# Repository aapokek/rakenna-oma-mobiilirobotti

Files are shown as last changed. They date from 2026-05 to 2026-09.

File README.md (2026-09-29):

<div align="center">

# 🤖 Rakenna oma mobiilirobotti 🤖

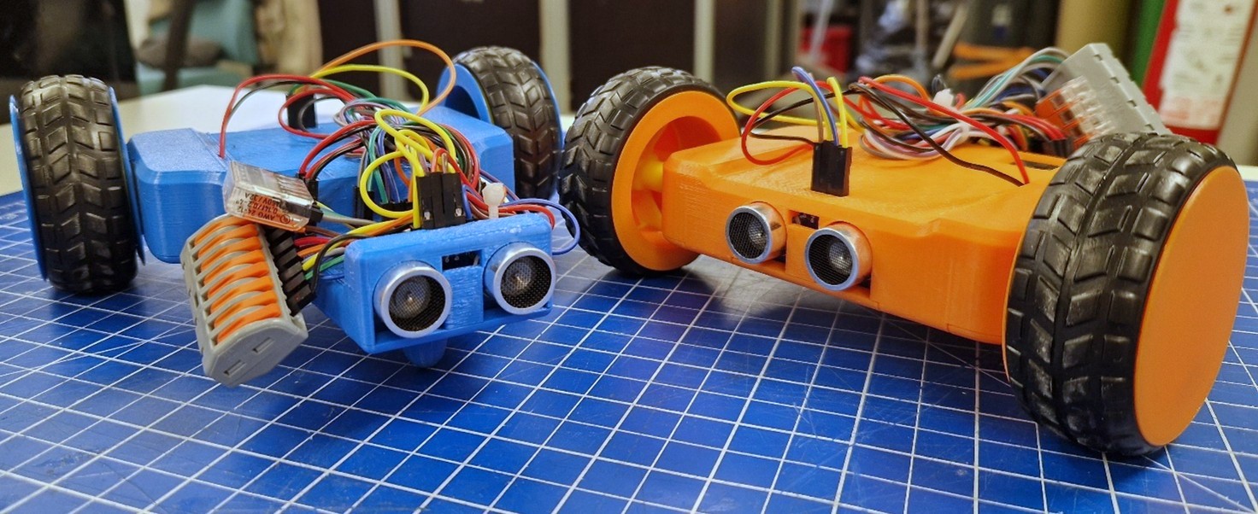
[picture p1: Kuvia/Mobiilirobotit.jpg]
Mobiilirobotit


**Rakenna oma WiFi-ohjattava mobiilirobotti törmäyksenestolla alusta loppuun!**



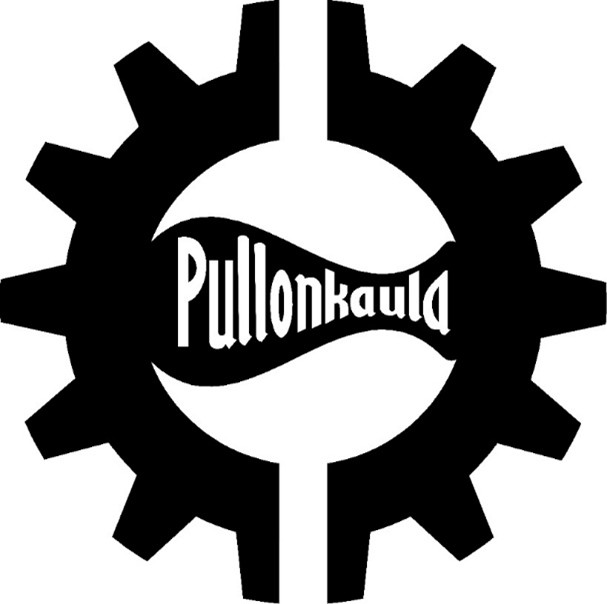
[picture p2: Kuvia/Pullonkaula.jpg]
Pullonkaula-kerho logo


*Pullonkaula ry*

</div>

---

## 📖 Tietoa projektista

Rakenna oma mobiilirobotti! Tämä projekti on alun pitäen saanut alkunsa Tampereen kaupungin Masseista mahiksia -tapahtumana syksyllä 2026. Tapahtumassa yläkoululaiset pääsivät rakentamaan oman mobiilirobotin, jota ohjataan älypuhelimella WiFin välityksellä. Robotti sisältää myös yksinkertaisen törmäyksenestojärjestelmän ultraääniantureiden avulla. Robotin kasausprosessi opettaa käytännön läheisesti sulautettujen järjestelmien toiminnan eli sen miten anturit ja toimilaitteet toimivat yhdessä!

Robotin kasaaminen ohjatusti sopii erinomaisesti kaikille – aiempaa kokemusta ei vaadita! Kokoneemmat rakentelijat voivat rakentaa robotin helposti itsenäisesti yksityiskohtaisen dokumentaation avulla!

---

## ✨ Ominaisuudet

- 📱 **WiFi-ohjaus** älypuhelimella selaimen kautta
- 🚧 **Törmäyksenesto** edessä ja takana
- 🖨️ **3D-tulostettu runko**
- ⚡ **AA-paristoilla** toimiva
- 🔧 **Helppo koota**
- 💰 **Kustannustehokas** – noin 20 € / kpl

---

## 🧰 Komponentit

| Komponentti | Määrä | Tehtävä |
|---|---|---|
| ESP8266 D1 mini | 1 | Mikrokontrolleri – robotin "aivot" |
| MP1584EN | 1 | Jännitteenmuuntaja (6V → 3.3V) |
| L298N mini + 470 µF | 1 | Moottorinohjain |
| HC-SR04 | 2 | Ultraäänianturit törmäyksenestoon |
| TT-moottori (1:48) | 2 | Liike |
| Rengas | 2 | Liike |
| 4×AA paristokotelo | 1 | Virtalähde |
| AA paristo (1.5 V) | 4 | Virtalähde |
| Vipuliittimet (3-, 5-, 8-napainen) | 1 kpl/tyyppi | Johdotus ilman juottamista |
| 0-0 hyppykaapelit | 8 | Kommunikaatiojohdot |
| 0-1 hyppykaapelit | 12 | Virtajohdot |
| M2×6 mm ruuvi | 3 | Rungon kiinnitys |
| Nippuside | 2 | Johtojen siistiminen |

> **Työkalut:** Tietokone, USB-C-kaapeli, ristipääruuvimeisseli, sivuleikkurit tai sakset

---

## 📁 Projektin rakenne

```
📦 Rakenna oma mobiilirobotti
├── 📂 3D-mallit
│   ├── 📂 Solidworks          ← Alkuperäiset SolidWorks-tiedostot
│   │   ├── Komponentit
│   │   └── Tulostettavat osat
│   ├── 📂 STEP                ← Universaali 3D-formaatti
│   └── 📂 STL                 ← Suoraan 3D-tulostimeen/Sliceriin!
├── 📂 Dokumentaatio
│   ├── Kasausohje (.pdf & .docx)
│   └── Build instructions (.pdf & .docx)
├── 📂 Koodit
│   └── Mobiilirobotin_koodi
│       └── Mobiilirobotin_koodi.ino   ← Arduino-koodi ESP8266:lle
└── 📂 Kuvia
    ├── Mobiilirobotin kytkentäkaavio.png
    ├── Mobiilirobotit.jpg
    ├── Kayttoliittyma.jpg
    └── Pullonkaula.jpg
```

---

## 🚀 Pikaopas kasaukseen

> 📄 Löydät täyden, yksityiskohtaisen ohjeen hakemistosta [`Dokumentaatio/`](Dokumentaatio/)  
> - Suomeksi: *Rakenna oma mobiilirobotti – Kasausohje* (.pdf / .docx)  
> - In English: *Build your own mobile robot – Build instructions* (.pdf / .docx)  
> 🎬 Tai katso kasausvideo: [youtu.be/AeR3-ane96E](https://youtu.be/AeR3-ane96E)

### 1️⃣ Koodin asennus

<details>
<summary><b>Asenna Arduino IDE</b></summary>

1. Mene osoitteeseen [arduino.cc/en/software](https://www.arduino.cc/en/software)
2. Lataa **Arduino IDE** omalle käyttöjärjestelmällesi (Windows / macOS / Linux)
3. Asenna ohjelma normaalisti asennusvelhon ohjeiden mukaan
4. Käynnistä Arduino IDE

</details>

<details>
<summary><b>Asenna ESP8266-tuki Arduino IDE:hen</b></summary>

1. Avaa Arduino IDE ja mene **File → Preferences**
2. Lisää **Additional boards manager URLs** -kenttään:
   ```
   https://arduino.esp8266.com/stable/package_esp8266com_index.json
   ```
3. Mene **Tools → Board → Boards Manager**, hae `esp8266` ja asenna **ESP8266 by ESP8266 Community**
4. Valitse piiriksi **Tools → Board → ESP8266 Boards → LOLIN(WEMOS) D1 mini (clone)**

</details>

<details>
<summary><b>Asenna tarvittavat kirjastot</b></summary>

Seuraavat kirjastot täytyy asentaa ennen koodin lataamista. Kirjastot löytyvät Arduino IDE:n kirjastonhallinnasta (**Tools → Manage Libraries…**) tai GitHub-linkeistä.

| Kirjasto | Asennus |
|---|---|
| `ESP8266WiFi` | Tulee automaattisesti ESP8266-tuen mukana |
| `DNSServer` | Tulee automaattisesti ESP8266-tuen mukana |
| `LittleFS` | Tulee automaattisesti ESP8266-tuen mukana |
| `ESPAsyncTCP` | Hae nimellä **ESPAsyncTCP** kirjastonhallinnasta |
| `ESPAsyncWebServer` | Hae nimellä **ESPAsyncWebServer** kirjastonhallinnasta |

> ⚠️ Jos `ESPAsyncTCP` tai `ESPAsyncWebServer` eivät löydy kirjastonhallinnasta, asenna ne manuaalisesti GitHubista:
> - [ESPAsyncTCP](https://github.com/me-no-dev/ESPAsyncTCP) → Code → Download ZIP → **Sketch → Include Library → Add .ZIP Library**
> - [ESPAsyncWebServer](https://github.com/me-no-dev/ESPAsyncWebServer) → sama menettely

</details>

Avaa `Koodit/Mobiilirobotin_koodi/Mobiilirobotin_koodi.ino` Arduino IDE:ssä. Muokkaa **riveille 2 ja 3** robotille haluamasi WiFi-verkon nimi ja salasana:

```cpp
String robotName = "MunRobotti";
static const char* AP_PASSWORD = "OmaSalasana"; // 8–63 merkkiä
```

Yhdistä ESP8266 D1 mini USB-C-kaapelilla tietokoneeseen ja paina Arduino IDE:ssä vasemman yläkulman **→ (Upload)**. Koodi on latautunut onnistuneesti, kun näet ilmoituksen `Done uploading`.

### 2️⃣ Komponenttien asennus runkoon

Tulosta ensin 3D-tulostettavat osat `3D-mallit/STL/`-kansiosta: ylärunko, alarunko, paristopidike sekä renkaiden pöly- ja sisäkapselit (2 kpl kumpaakin).

Työnnä moottoreiden johdot ylärungon sivureikien läpi ja paina moottorit paikoilleen. Paina sitten ESP8266 D1 mini, MP1584EN, L298N mini sekä molemmat HC-SR04-anturit niille tulostettuihin loviin. Asenna lopuksi AA-paristot paristokoteloon (kytkin OFF-asennossa!) ja kiinnitä paristopidike paikoilleen. Asenna alarunko pohjaksi, mutta jätä ruuvit vielä kiinnittämättä.

### 3️⃣ Virtajohtojen kytkeminen

Kytke robotin 18 virtajohtoa (12 toteutetaan 0-1 hyppykaapeleilla) kytkentäkaavion mukaisesti: kaikki maajohdot (GND) suurimpaan 8-napaiseen vipuliittimeen, paristoilta tuleva 6 V 3-napaiseen liittimeen ja MP1584EN:n antama 3.3 V 5-napaiseen liittimeen. Kytke myös moottorien johdot L298N minin MOTOR-A ja MOTOR-B -pinneihin.

### 4️⃣ Kommunikaatiojohtojen kytkeminen

Kytke 8 kommunikaatiojohtoa 0-0 hyppykaapeleilla ESP8266 D1 miniin kytkentäkaavion mukaisesti. Katso kytkentäkaavio alta! ⬇️

### 5️⃣ Testaus

> ⚠️ **Tarkastuta kytkennät huolella ennen testauksen aloittamista!**

Kiinnitä renkaat paikoilleen ja käynnistä robotti paristokotelon kytkimestä. Yhdistä puhelimella robotin WiFi-verkkoon ja avaa selaimessa `192.168.4.1` (jos ohjausnäkymä ei avaudu automaattisesti). Näytöllesi pitäisi ilmestyä alla näkyvä ohjausnäkymä.

<div align="center">
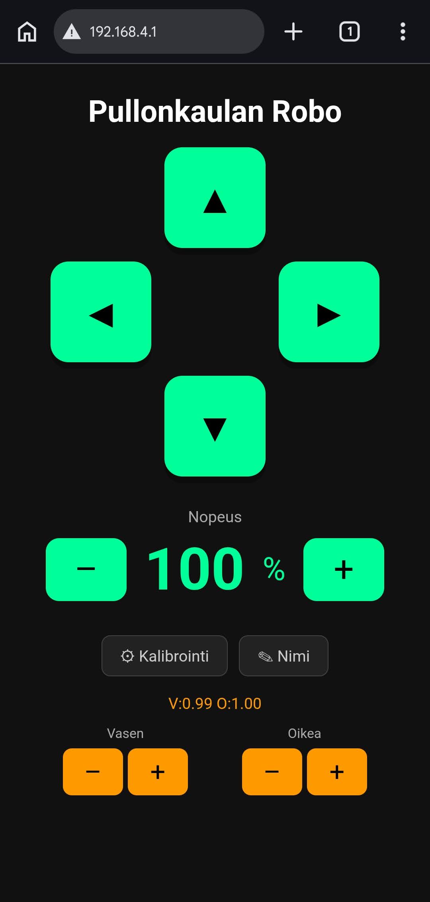
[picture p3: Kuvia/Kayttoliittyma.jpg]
Robotin ohjaukseen käytettävä käyttöliittymä puhelimen selaimessa

</div>

Ohjaa robottia napeista – jos jompikumpi moottori pyörii väärään suuntaan, vaihda sen virtajohdot päikseen.

### 6️⃣ Viimeistely

Ruuvaa pohja kiinni kolmella M2-ruuvilla ja siisti johdot kahdella nippusiteellä. Voit halutessasi kalibroida robotin kulkemaan suoraan sekä nimetä sen uudelleen käyttöliittymän valikoista.

---

## 🔌 Kytkentäkaavio

<details>
<summary><b>Näytä kytkentäkaavio</b></summary>

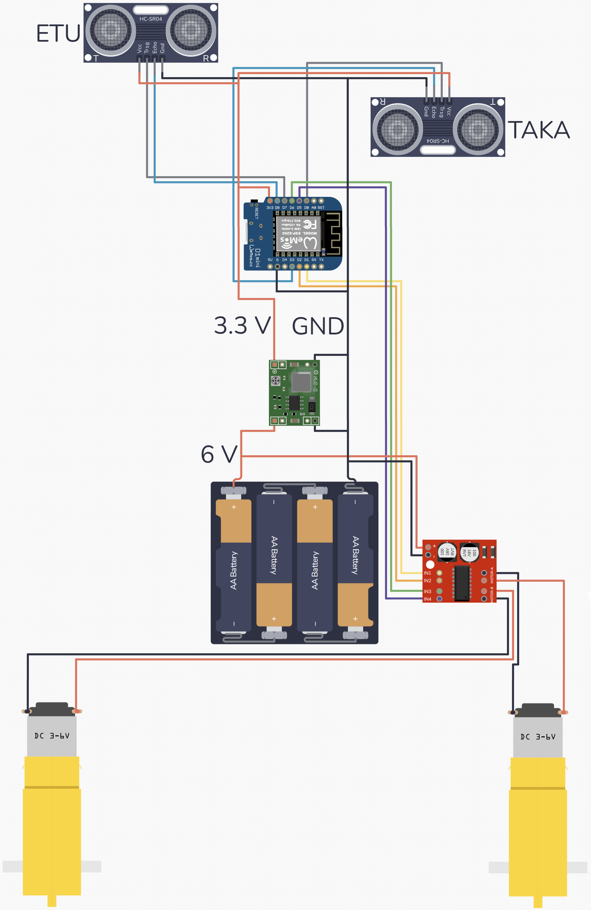
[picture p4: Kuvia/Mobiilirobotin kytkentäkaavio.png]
Kytkentäkaavio


**Pääperiaate:**
- 🔴 **6 V** (paristot) → L298N mini ja MP1584EN sisääntulo
- 🟠 **3.3 V** (MP1584EN ulostulo) → ESP8266 D1 mini ja HC-SR04-anturit
- ⚫ **GND** → kaikki komponentit yhteiseen 8-napaiseen vipuliittimeen

**Kommunikaatiojohdot (ESP8266):**

| L298N / HC-SR04 | ESP8266-pinni |
|---|---|
| IN1 | D1 |
| IN2 | D2 |
| IN3 | D6 |
| IN4 | D5 |
| Etuanturi Trig | D7 |
| Etuanturi Echo | D8 |
| Takaanturi Trig | D0 |
| Takaanturi Echo | D3 |

</details>

---

## 🎬 Kasausvideo

Kasausvideo (https://youtu.be/AeR3-ane96E)

---

## 📜 Lisenssi

Tämä projekti on kehitetty opetuksellisiin tarkoituksiin ja sen kaupallinen käyttö on kielletty.
Kehittäjä: **Aapo Kekkonen**

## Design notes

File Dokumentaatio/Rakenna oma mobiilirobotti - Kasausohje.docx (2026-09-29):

# Rakenna oma mobiilirobotti

# Kasausohje

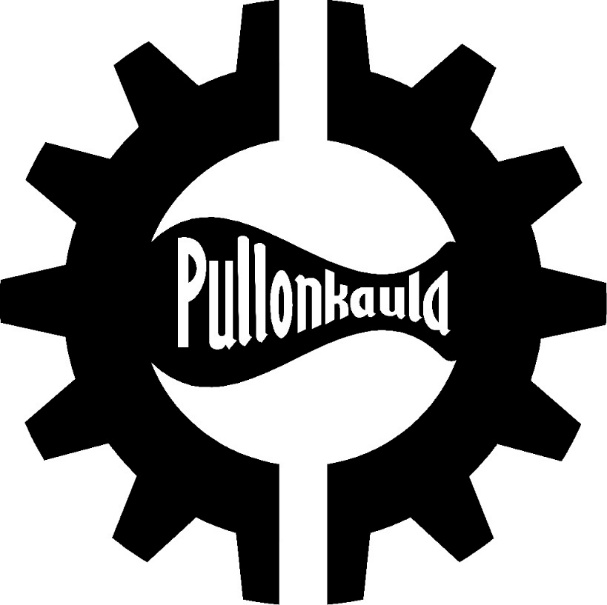
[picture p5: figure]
Blogi | Pullonkaula ry
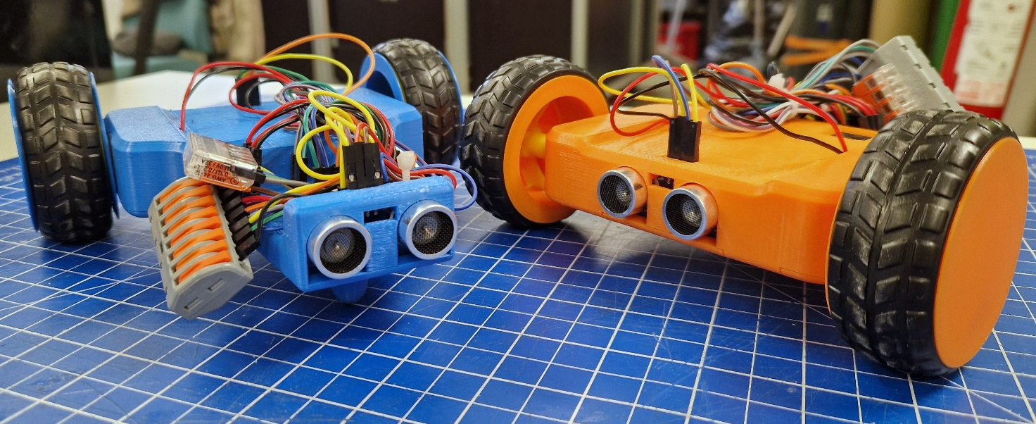
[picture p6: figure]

# Johdanto

Tervetuloa kasaamaan omaa mobiilirobottia!

Rakennettava mobiilirobotti ei jätä sinua kylmäksi, sillä sen ohjaus onnistuu omalla mobiililaitteellasi. Tämän lisäksi robotti sisältää yksinkertaisen törmäyksenestojärjestelmän.

Rakennettuasi robotin ymmärrät perusteet toimilaitteiden ja antureiden muodostamasta sulautetusta järjestelmästä! Samaa toimilaitteiden ja antureiden yhteyspeliä hyödyntävät myös muut robotit.

Tämä ohje aloittaa opastuksen luettelemalla tarvittavat komponentit ja antamalla lisätietoa komponenteista. Tämän jälkeen kasausprosessi käydään läpi yksityiskohtaisesti. Lopusta löydät vielä yksinkertaistetun kytkentäkaavion.

Oheisesta QR-koodista tai linkistä löydät videon kasausprosessista.

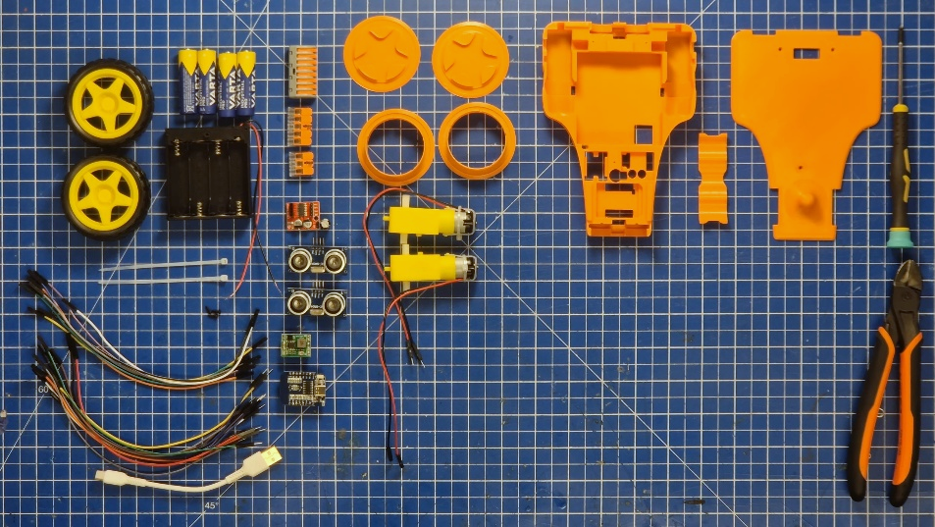
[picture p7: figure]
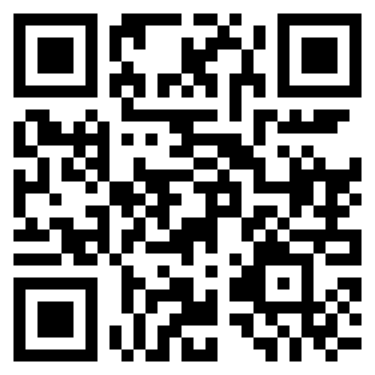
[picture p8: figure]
QR Code Image

https://youtu.be/AeR3-ane96E

Lisäksi oheisesta QR-koodista tai linkistä pääset robotin projektisivuille, josta löydät kaikki projektiin liittyvät tiedostot mukaan lukien myös tämän ohjeen!

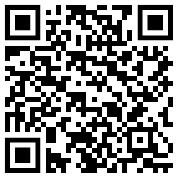
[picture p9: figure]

https://github.com/aapokek/Rakenna-oma-mobiilirobotti

# Tarvikkeet

Oheisesta taulukosta näet robotin rakentamiseen tarvittavat komponentit ja työkalut. Taulukko on jaoteltu 3D-tulostettaviin osiin, komponentteihin ja työkaluihin. 3D-tulostettavien osien tiedostot löydät projektikansiosta (Rakenna-oma-mobiilirobotti/3D-mallit/). Jos haluat tulostaa osia itse, hyödynnä siihen STL tai STEP tiedostoja. Lue halutessasi lisää komponenteista ja niiden käyttötarkoituksista seuraavasta kappaleesta!

# Tietoa komponenteista

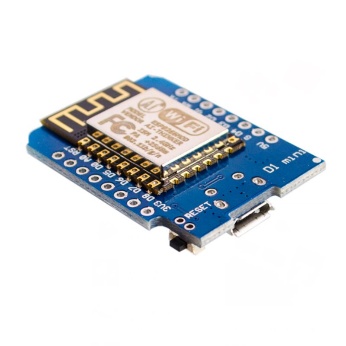
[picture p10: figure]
WeMos D1 Mini v2 NodeMCU ESP8266 IoT-kehitysalusta | ihmevekotin.fi

## ESP8266 D1 mini

ESP8266 D1 mini toimii robotin aivoina. Siihen ladataan ohjelmisto, jolla älypuhelimen ohjaussignaali muutetaan moottoreiden liikkeeksi. Lisäksi se lukee etäisyystietoja HC-SR04 etäisyysantureilta ja pysäyttää liikkeen havaitessa esteen riittävän lähellä. L298N mini moottorinohjain ja HC-SR04-anturit liitetään ESP8266 D1 minin sivussa oleviin nimettyihin liitinpinneihin.

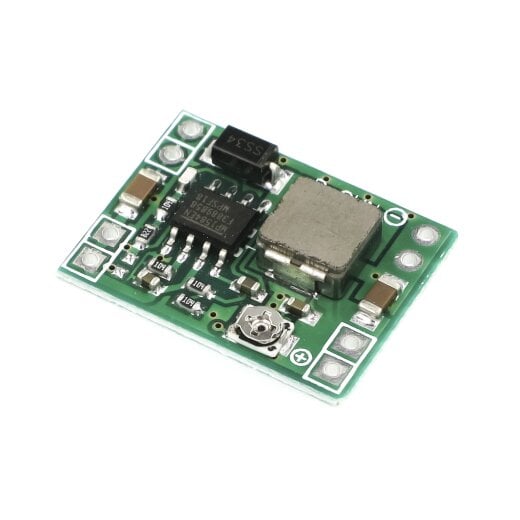
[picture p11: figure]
Mini DC-DC Step-down Spannungsregler MP1584EN Buck-virtamoduulin lähtö 0,8--20V 3A
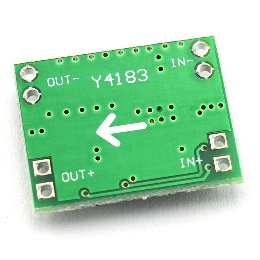
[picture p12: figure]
Opencircuit MP1584EN Mini Buck -muunnin 4,5 V - 28 V moduuli

## MP1584EN

MP1584EN on jännitteen muuntaja, joka muuntaa ja tasaa AA paristoilta tulevan 6 V jännitteen 3.3 volttiin. Tämä 3.3 V jännite syötetään ESP8266 D1 minille ja HC-SR04-antureille. Huomioithan komponentin takana olevan muunnoksen suuntanuolen. Voit liittää virtajohdon kumpaan tahansa vierekkäin olevaan pinniin.

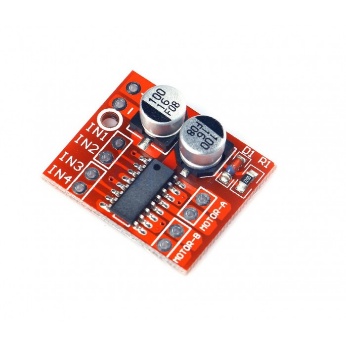
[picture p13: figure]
Mini L298N Motor Driver

## L298N mini + 470 µF

L298N mini ohjaa robotin moottoreita ESP8266 D1 minin
lähettämien signaalien mukaisesti. L298N minissä on 10
liitäntäpinniä. Komponentti saa virran suoraan paristolta +/-
pinneihin. Itse moottorit kiinnittyvät MOTOR-A ja MOTOR-B pinneihin. Vaihtamalla moottoripinnien kytkentä päikseen, moottorien pyörintäsuunta vaihtuu. Moottoreiden ohjaus
tapahtuu IN1, IN2, IN3 ja IN4 pinneillä, jotka kytketään
ESP8266 D1 miniin. Pinnit IN1 ja IN2 ohjaavat moottoria A ja IN3 ja IN4 moottoria B seuraavan taulukon mukaisesti:

Moottorin tila | IN1/IN3 | IN2/IN4
Eteenpäin | PWM | 0 V
Taaksepäin | 0 V | PWM
Valmiustila | 0 V | 0 V
Jarrutus | 3.3 V | 3.3 V

Taulukossa esiintyvän PWM:n (Pulse Width Modulation) avulla säädellään moottoreiden pyörimisnopeuksia. L298N minin virtapinneihin on juotettu 470 µF kondensaattori tasaamaan moottoreiden mahdollisia virtapiikkejä ja parantamaan moottoreiden suorituskykyä.

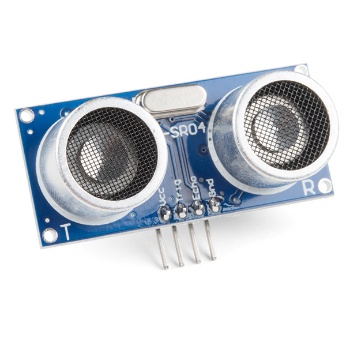
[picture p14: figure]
Ultrasonic Sensor - HC-SR04

## HC-SR04

HC-SR04 on ihmisen kuuloalueen ulkopuolisilla ultraäänipulssein toimiva etäisyysanturi. Sen toiminta perustuu esteen aiheuttamaan kaikuun. Anturi lähettää lyhyitä ultraäänipulsseja ja kuuntelee samaisten pulssien kaikuja. Anturi pystyy havaitsemaan esteen jopa 4 metrin päästä. HC-SR04:n 4 pinniä ovat VCC, GND, Trig ja Echo. Virta syötetään pinneihin VCC ja GND. Trig-pinniä hyödynnetään pulssin lähetykseen. Kaiun kuullessa anturi lähettää signaalin Echo-pinniin, joka rekisteröidään ESP8266:lla. Robotissa kyseisiä antureita käytetään törmäysten estoon eteenpäin tai taaksepäin liikkuessa. ESP8266 D1 mini laskee etäisyyden esteestä pulssin lähetyksen ja vastaanoton aikaerosta. Valmiissa koodissa robotti on asetettu pysähtymään asetetun nopeuden mukaan 20–50 cm etäisyydellä esteestä.

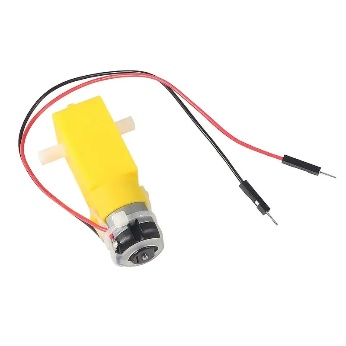
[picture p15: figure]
TT DC Motor with Plastic Gearbox – 1:48 Dual Shaft with Wires – Voltaat

## Moottorit

Robottia liikuttaa pienet 1:48 vaihteistolliset moottorit. Keltainen vaihteisto mahdollistaa robotille riittävän väännön liikkumista varten. Itse moottori on vaihteiston toisessa päässä ja sitä ohjataan syöttämällä 3–6 V jännite virtajohtoihin. Moottoreiden ohjauksen suorittaa L298N mini ja moottorin johdot kytketään sen MOTOR-A tai MOTOR-B pinneihin. Moottorin pyörimissuunnan voi vaihtaa yksinkertaisesti vaihtamalla johdot päikseen.

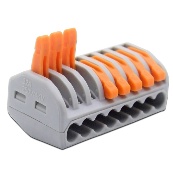
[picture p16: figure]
8-pinninen pikaliitin (Wago tyyppinen) – Pekan Sähkökiituri

## Vipuliittimet

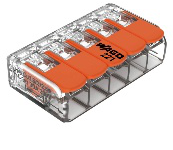
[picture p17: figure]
Wago 5-napainen vipuliitin 6 mm² 6 kpl | Motonet Oy

Vipuliittimet ovat helppokäyttöisiä kaapeliliittimiä, joilla voidaan liittää kaksi tai useampi kaapeli yhteen nopeasti ja ilma juottamista. Vipuliittimen toimintaperiaate on yksinkertainen: Ensin vipu avataan, sitten kaapeli työnnetään liittimeen ja lopulta vipu suljetaan. Robotissa käytetään 3-, 5- ja 8-napaisia vipuliittimiä virtajohtojen liittämiseen. Kaikki maajohdot (GND/-) kytketään suurimpaan 8-napaiseen liittimeen. Paristoilta tuleva 6 V jännite jaetaan 3-napaiseen liittimeen ja 3.3 V jännite 5-napaiseen liittimeen.

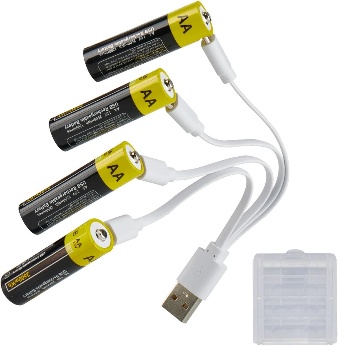
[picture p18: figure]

## AA-paristot

Robotti saa virtansa neljästä normaalista AA paristosta. Voit halutessasi käyttää myös ladattavia AA-paristoja, mutta niiden tulee olla 1.5 V litiumparistoja (esimerkiksi kuvan kaltaisia). Huomaathan, että normaalit ladattavat AA-paristot ovat usein NiMH-akkukemiallisia ja täten soveltumattomia 1.2 V jännitteellään.

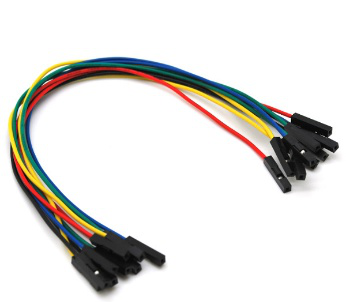
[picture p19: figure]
Premium Jumper Wires Female-Female 250 mm Bundle of 10 – Rocket Scream

## Hyppykaapelit

Komponentit liitetään toisiinsa hyppykaapeleilla, joita on olemassa kolmea eri tyyppiä: 0-0, 0-1 ja 1-1. Hyppykaapelit mahdollistavat nopeiden liitosten tekemisen, sillä liitosta ei tarvitse juottaa. Robottiin käytetään 8 0-0 hyppykaapelia ja 12 0-1 hyppykaapelia.

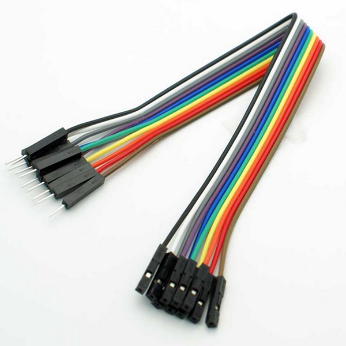
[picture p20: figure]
10-Way F/M Jumper Wire 20cm – HandsOn Tech

# Kasausprosessi

Robotin kasausprosessi on kuusivaiheinen ja siirtyy koodin asentamisen kautta komponenttien kiinnittämiseen ja johtojen vedon kautta testaukseen sekä viimeistelyyn. Tämän ohjeen viimeiseltä sivulta löydät kytkentäkaavion auttamaan kytkentöjen tekoa.

## 1. Koodin asennus

Kasausprosessi alkaa koodin asentamisella ESP8266 D1 miniin. Anna valmiin koodin riveille 2 ja 3 robotin nimi ja käytettävä salasana.

String robotName = "MunRobotti";

static const char* AP_PASSWORD = "OmaSalasana";

Tulet myöhemmin yhdistämään nimen mukaiseen wifi-verkkoon antamallasi salasanalla. Muokkausten jälkeen voit yhdistää ESP8266 D1 minin USB-kaapelilla tietokoneeseen ja painaa Arduino IDE:n vasemman yläkulman sinistä nuolta. Koodi on ladattu onnistuneesti, kun saat ilmoituksen ”Done uploading”. Tämän jälkeen voit irrottaa USB-kaapelin ja jatkaa seuraavaan vaiheeseen.

## 2. Komponenttien asentaminen runkoon

Seuraavaksi asennetaan kaikki elektroniikkakomponentit 3D-tulostettuun ylärunkoon.

Työnnä ensin moottoreiden johdot sivussa olevien reikien läpi ja paina moottorit varovasti paikoilleen. Varmista, että johdot suoristuvat eivätkä jää puristuksiin moottorin alle.

Paina seuraavat komponentit niille tulostettuihin loviin:

1. ESP8266 D1 mini
2. MP1584EN
3. L298N mini + 470 µF
4. Molemmat HC-SR04-anturit

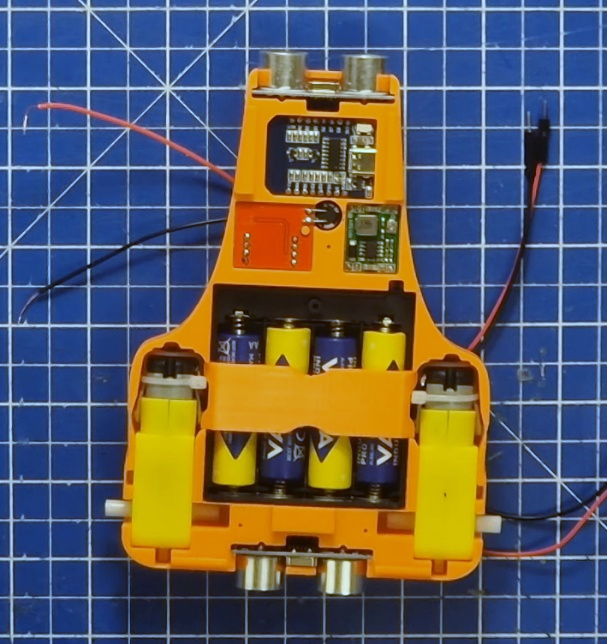
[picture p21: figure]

Ota seuraavaksi paristokotelo ja varmista, että sen kytkin on OFF-asennossa välttääksesi oikosulun riskin. Asenna AA-paristot paikoilleen. Reititä paristojen johto pienen loven läpi ja työnnä paristokotelo kohdilleen paristot osoittaen ylöspäin. Tämän jälkeen voit painaa 3D-tulostetun paristopidikkeen paikoilleen. Pidikkeen tehtävänä on varmistaa paristojen pysyminen kotelossa ilman kotelon alkuperäistä kantta. Voit myös käyttää kotelon mukana tullutta kantta, mutta paristojen vaihtaminen on tällöin työläämpää.

Loistavaa työtä! Edellisten vaiheiden jälkeen robottisi tulisi näyttää kutakuinkin oheisen kuvan mukaiselta!

Asenna robotin alarunko robotin pohjaksi. Jätä ruuvien kiinnittäminen viimeistelyvaiheeseen, kunnes robotti on testattu. Käännä robotti ympäri johtojen kytkemistä varten.

3. Virtajohtojen kytkeminen

Tässä vaiheessa kytkemme robotin kaikki virtajohdot. Tämä tarkoittaa kytkentäkaavion kaikkia punaisia ja mustia johtoja. Robotissa on yhteensä 18 virtajohtoa, joista 12 toteutetaan 0-1 hyppykaapeleilla.

Aloita virtajohtojen kytkentä liittämällä moottoreiden virtajohdot L298N minin MOTOR-A ja MOTOR-B pinneihin. Moottorin johtojen kytkeminen toisin päin vaihtaa moottorin pyörimissuunnan. Muista tämä testausvaiheessa, jos joku moottoreista pyörii väärään suuntaan. Kytkentäkaavion kytkentöjen järjestys on todettu toimivaksi.

Loput virtajohdot voit kytkeä haluamassasi järjestyksessä, mutta varmista toteuttavasi seuraavat vaiheet.

Maadoitusjohtojen kytkennät:

- Pariston musta johto (ei hyppykaapeli) → 8-napainen vipuliitin
- ESP8266 D1 mini G → 8-napainen vipuliitin
- MP1584EN IN- → 8-napainen vipuliitin
- MP1584EN OUT- → 8-napainen vipuliitin
- L298N mini - → 8-napainen vipuliitin
- Etummaisen HC-SR04 Gnd → 8-napainen vipuliitin
- Takimmaisen HC-SR04 Gnd → 8-napainen vipuliitin

6 V kytkennät:

- Pariston punainen johto (ei hyppykaapeli) → 3-napainen vipuliitin
- MP1584EN IN+ → 3-napainen vipuliitin
- L298N mini + → 3-napainen vipuliitin

3.3 V kytkennät:

- MP1584EN OUT+ → 5-napainen vipuliitin
- ESP8266 D1 mini 3V3 → 5-napainen vipuliitin
- Etummainen HC-SR04 Vcc → 5-napainen vipuliitin
- Takimmainen HC-SR04 Vcc → 5-napainen vipuliitin

## 4. Kommunikaatiojohtojen kytkeminen

Nyt kun kaikki komponentit saavat virtaa on aika kytkeä kommunikaatiojohdot!

Robotissa on yhteensä 8 kommunikaatiojohtoa, joiden kytkennät toteutetaan 0-0 hyppykaapeleilla. Huomaathan, että jokaisen kommunikaatiojohdon toinen pää on kiinni robotin aivoissa eli ESP8266 D1 minissä.

Tee seuraavat kytkennät:

- L298N mini IN1 → ESP8266 D1
- L298N mini IN2 → ESP8266 D2
- L298N mini IN3 → ESP8266 D6
- L298N mini IN4 → ESP8266 D5
- Etummainen HC-SR04 Trig → ESP8266 D7
- Etummainen HC-SR04 Echo → ESP8266 D8
- Takimmainen HC-SR04 Trig → ESP8266 D0
- Takimmainen HC-SR04 Echo → ESP8266 D3

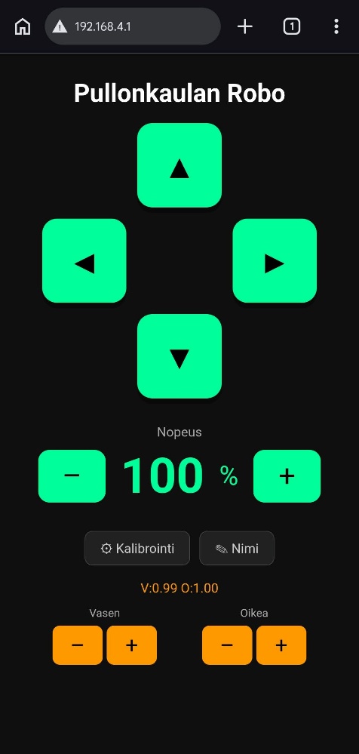
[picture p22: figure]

## 5. Testaus

Tarkastuta tekemäsi kytkennät tapahtuman ohjaajan kanssa ennen testauksen aloittamista!

Nyt robottisi on toimintavalmis ja valmis ensimmäistä testausta varten!

Asenna renkaisiin 3D-tulostetut pöly- ja sisäkapselit, kiinnitä renkaat paikoilleen ja käännä virrat päälle paristokotelon kytkimestä. ESP8266 D1 mini väläyttää käynnistyessään sinistä valoa. Voit tämän jälkeen ottaa älypuhelimesi esiin ja navigoida WIFI-asetuksiin. Etsi täältä robotin nimen mukainen verkko ja yhdistä siihen asettamallasi salasanalla. Yhdistyttyäsi verkkoon puhelin saattaa mennä automaattisesti ohjausnäkymään. Jos mitään ei kuitenkaan tapahdu yhdistämisen jälkeen, avaa puhelimesi verkkoselain ja kirjoita hakukenttään IP-osoite 192.168.4.1. Näytöllesi pitäisi lopulta ilmestyä oheisen kuvan mukainen käyttöliittymä!

Varmista robotin toimivuus painelemalla ohjausnappeja. Jos huomaat jommankumman tai molempien moottoreiden pyörivän epäloogiseen suuntaan, vaihda kyseisen moottorin virtajohtojen paikat päikseen.

## 6. Viimeistely

Viimeistellään robotti ruuvaamalla robotin pohjaan kolme kiinnitysruuvia. Laitetaan lopuksi johdot nippuun kahdella nippusiteellä. Huomaa rungon kaksi nippusiteiden kiinnityspaikkaa. Voit halutessasi kalibroida robottisi kulkemaan suoraan käyttöliittymän kalibrointivalikosta, jossa voit vähentää jommankumman puolen moottorin pyörimisnopeutta. Voit lisäksi uudelleennimetä robottisi nimivalikosta. Huomaathan, että uudelleennimeämisen jälkeen sinun tulee yhdistää uudella nimellä varustettuun verkkoon asettamallasi salasanalla.

Onnittelut, robottisi on nyt käyttövalmis!

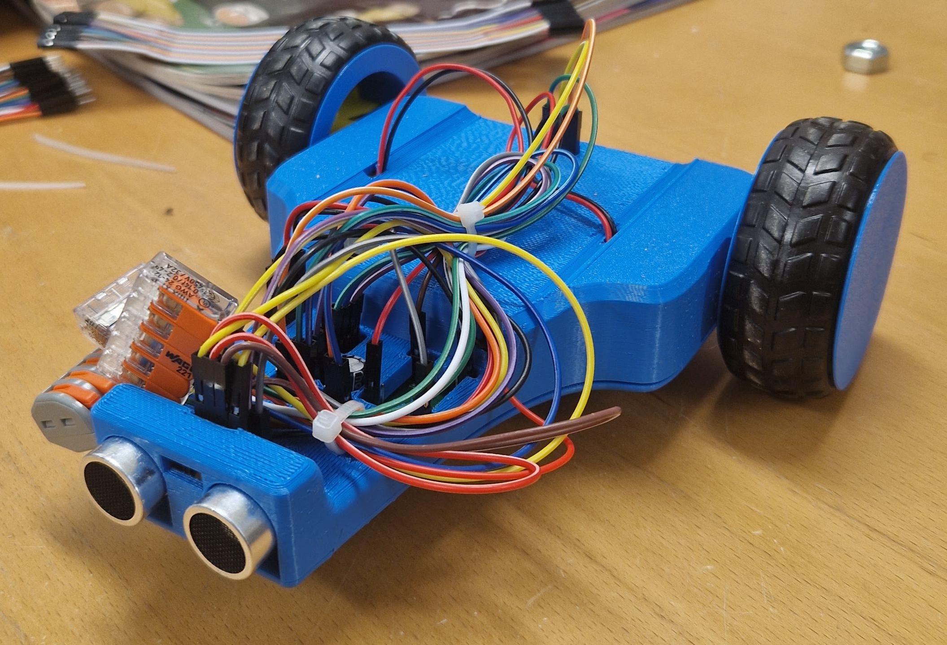
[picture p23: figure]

## Lisähuomioita

Paristot kestävät aktiivisessa käytössä jopa useita tunteja, kunhan muistat sammuttaa robotin virrat käytön jälkeen. Huomaat paristojen vajenemisen äkkinäisistä yhteyden menetyksistä. Jos haluat ajaa robotilla paljon, suosittelemme hankkimaan ladattavat 1.5 V AA-litiumakut (ei NiMH), joiden hintahaarukka on 20-30 €/4 kpl. Näitä myydään usein usb-c ladattavina, jolloin erillistä laturia ei tarvita.

Voit halutessasi tutustua robotin koodiin, jonka löydät projektikansiosta (Rakenna-oma-mobiilirobotti/Koodit/Mobiilirobotin_koodi/Mobiilirobotin_koodi.ino).

Saat muokata koodia haluamaksesi (omalla vastuulla) ja päivittää täten robotin koodin. Muista kytkeä paristojen virta pois päältä kytkettäessä USB-C kaapelia ESP8266:seen. Löydät lisätietoja koodin asentamiseen omalla tietokoneella projektikansion etusivulta osiosta ”Koodin asennus”.

# Kytkentäkaavio

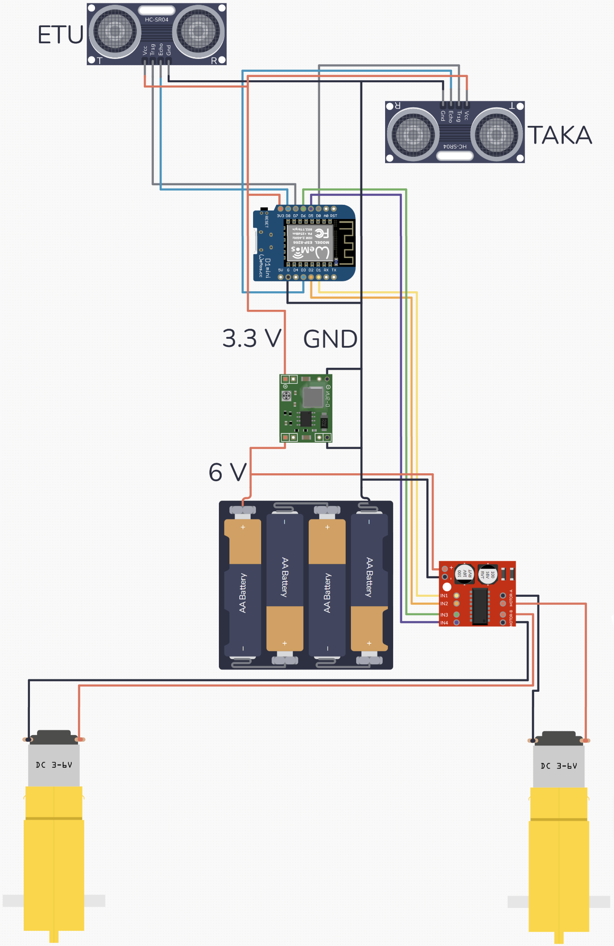
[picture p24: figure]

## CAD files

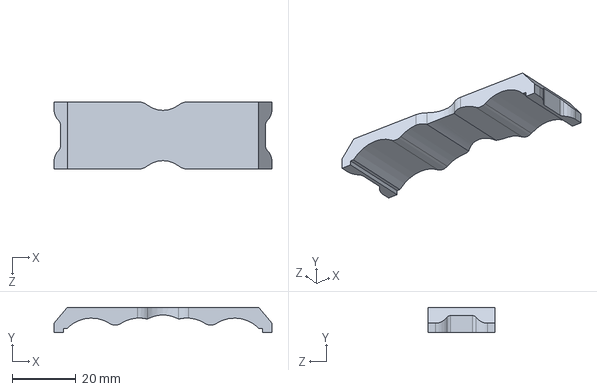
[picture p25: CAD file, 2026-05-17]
3D-mallit/Solidworks/Tulostettavat osat/Rakenna oma mobiilirobotti - Paristopidike.SLDPRT
68.5 x 8.00 x 21.2 mm

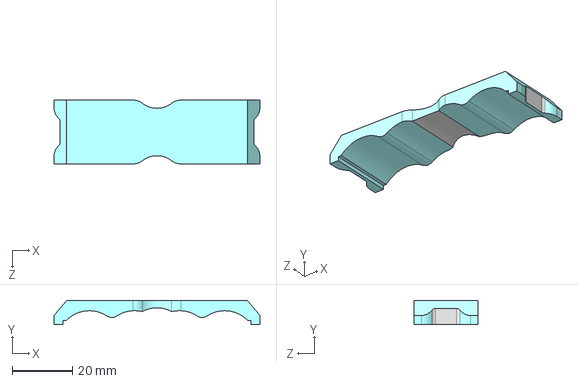
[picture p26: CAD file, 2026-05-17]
3D-mallit/STEP/Rakenna oma mobiilirobotti - Paristopidike.STEP
68.5 x 8.00 x 21.2 mm

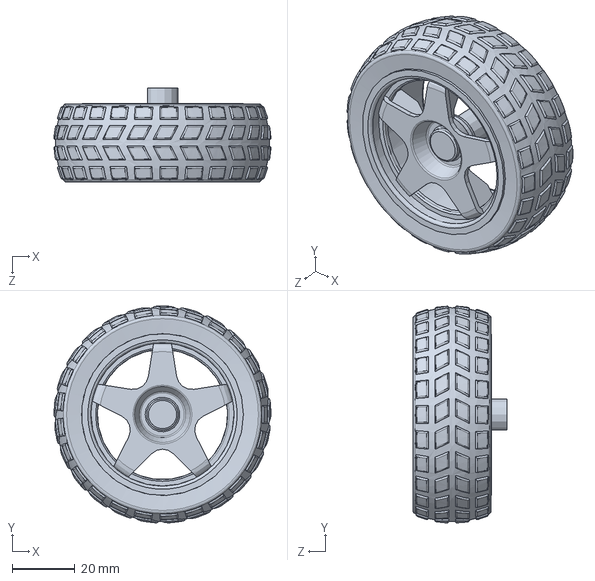
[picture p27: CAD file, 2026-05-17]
3D-mallit/Solidworks/Komponentit/Wheel D65x25.SLDPRT
68.9 x 68.8 x 30.0 mm

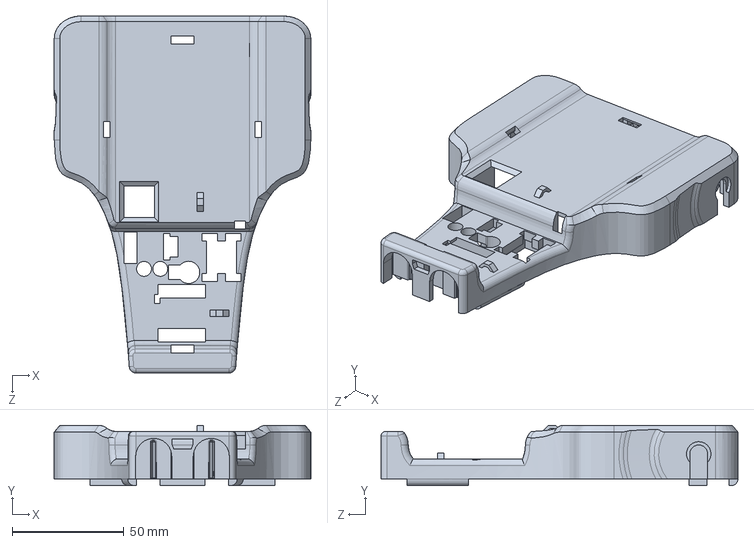
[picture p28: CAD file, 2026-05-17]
3D-mallit/Solidworks/Tulostettavat osat/Rakenna oma mobiilirobotti - Ylärunko.SLDPRT
115.0 x 27.0 x 160.0 mm

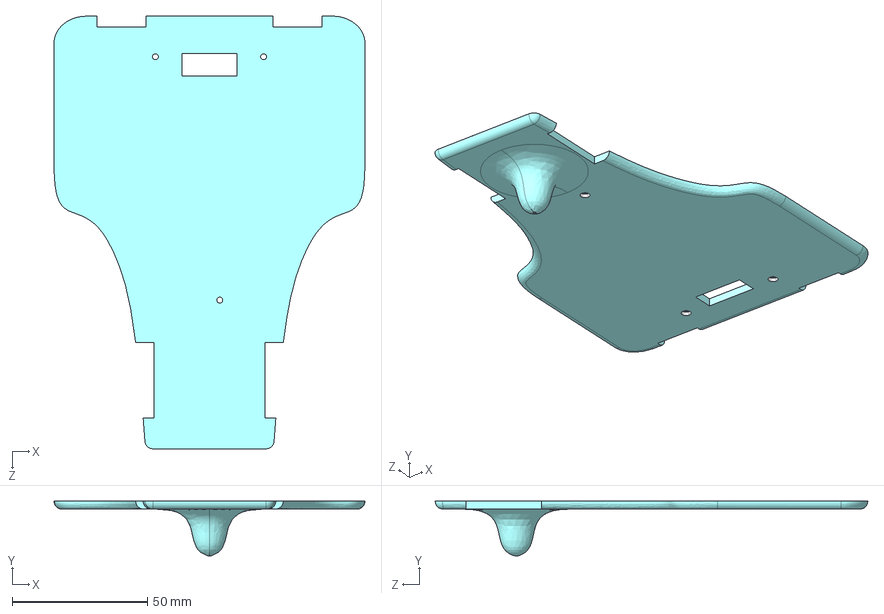
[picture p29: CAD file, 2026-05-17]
3D-mallit/STEP/Rakenna oma mobiilirobotti - Alarunko.STEP
115.0 x 20.3 x 160.0 mm

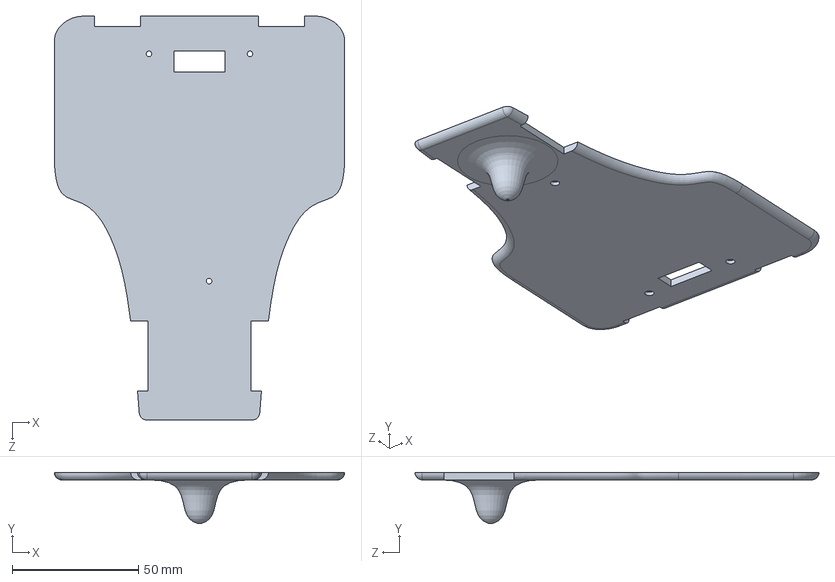
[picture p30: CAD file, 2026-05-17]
3D-mallit/Solidworks/Tulostettavat osat/Rakenna oma mobiilirobotti - Alarunko.SLDPRT
115.0 x 20.3 x 160.0 mm

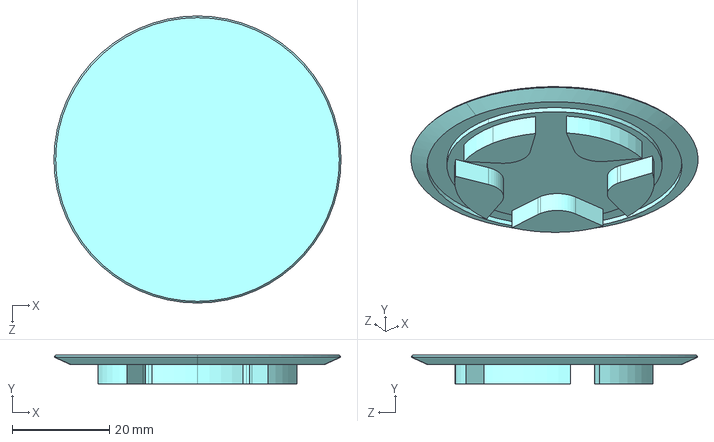
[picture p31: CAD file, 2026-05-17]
3D-mallit/STEP/Rakenna oma mobiilirobotti - Pölykapseli.STEP
59.0 x 5.90 x 59.0 mm

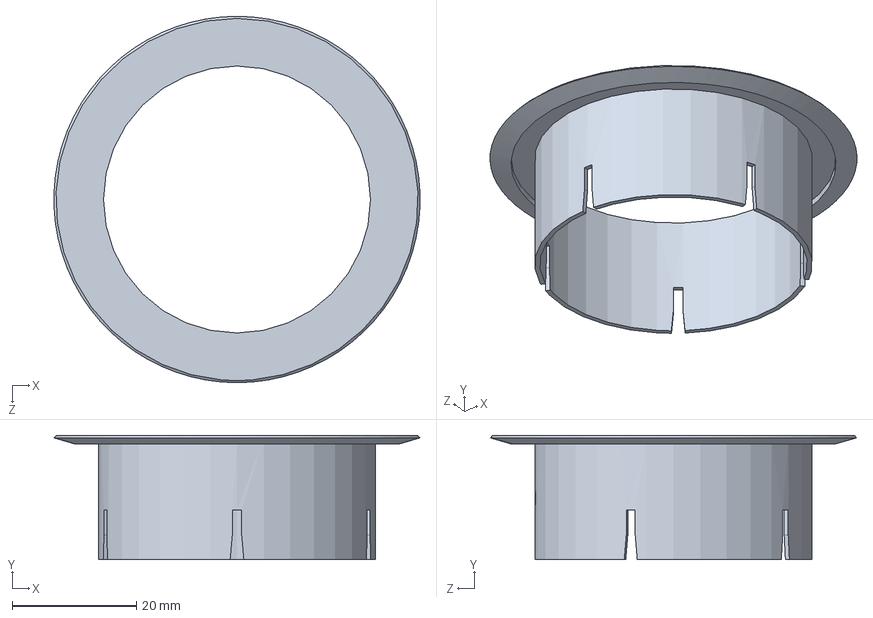
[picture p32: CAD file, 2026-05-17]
3D-mallit/Solidworks/Tulostettavat osat/Rakenna oma mobiilirobotti - Sisäkapseli.SLDPRT
58.9 x 20.0 x 59.0 mm

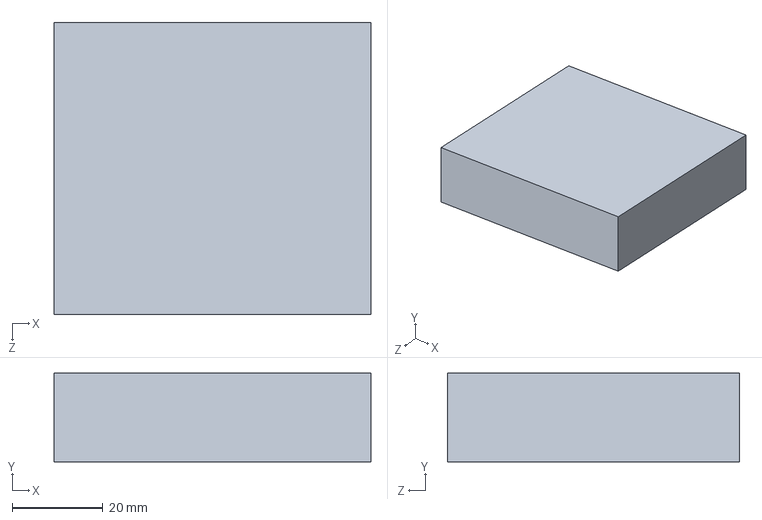
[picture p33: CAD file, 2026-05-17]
3D-mallit/Solidworks/Komponentit/Battery Holder.SLDPRT
69.8 x 19.5 x 64.4 mm

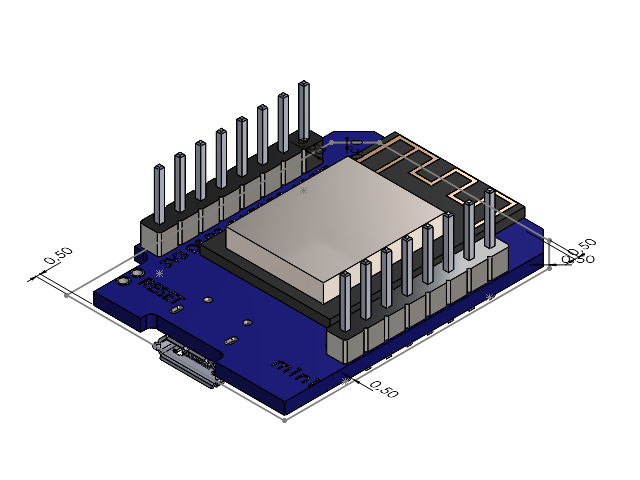
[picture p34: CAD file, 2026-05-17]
3D-mallit/Solidworks/Komponentit/ESP8266.SLDASM
WEMOS-D1-mini_detailed
Pin_header_str_1x08_p2_54mm x 2

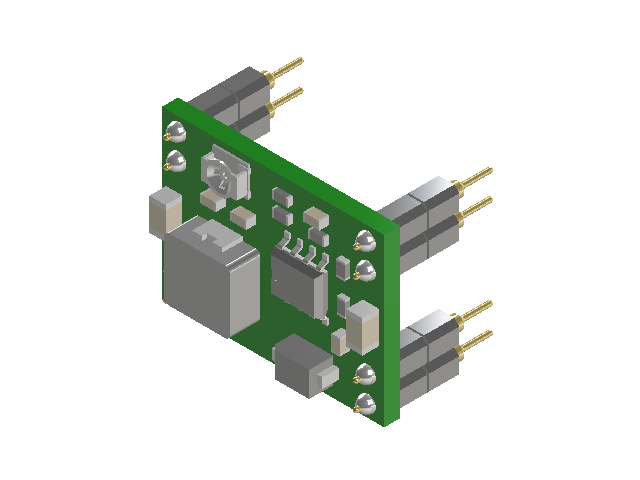
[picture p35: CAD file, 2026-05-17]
3D-mallit/Solidworks/Komponentit/MP1584EN.SLDASM
SOP-8L_001.step
1x2 Male Header_001.step
1x2 Male Header_002.step
1x2 Male Header_003.step
1x2 Male Header_004.step
1x2 Female Header_001.step
1x2 Female Header_002.step
1x2 Female Header_003.step
1x2 Female Header_004.step
Inductor_001.step
Body_001.step
1206 Capacitor_001.step
1206 Capacitor_002.step
0603 Capacitor_001.step
0603 Capacitor_002.step
0603 Capacitor_003.step
0603 Capacitor_004.step
0603 Resistor_001.step
0603 Resistor_002.step
0603 Resistor_003.step
0603 Resistor_004.step
0603 Resistor_005.step
Diode_001.step
Trim Pot_001.step

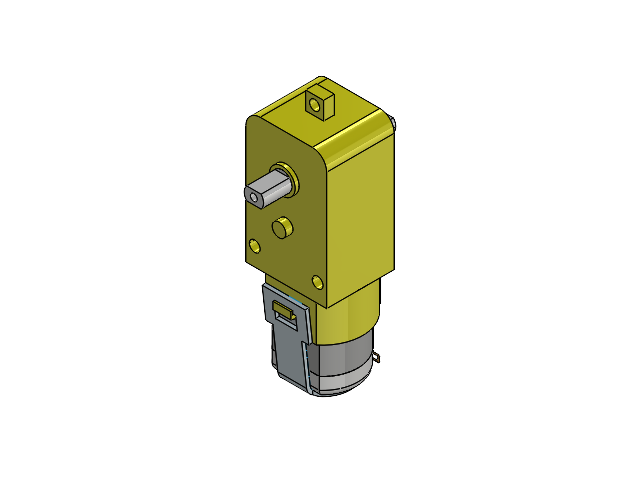
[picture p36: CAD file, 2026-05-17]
3D-mallit/Solidworks/Komponentit/TT Motor Dual Shaft.SLDASM
Part 8.step
Surface 1.step
Part 7.step
Part 6.step
Part 5.step
Part 4.step
Part 3.step
Part 2.step
Part 1.step

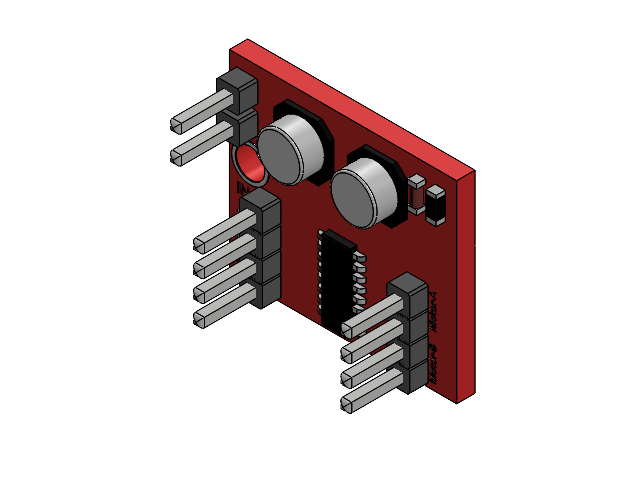
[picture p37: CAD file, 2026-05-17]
3D-mallit/Solidworks/Komponentit/L298N mini.SLDASM
Component1.step
Component2.step
Component3.step
Component4.step
Component5.step
Component6.step
eBom-FreeParts.step
Body1_1.step x 10
Body2_1.step x 10

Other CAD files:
3D-mallit/STEP/Rakenna oma mobiilirobotti - Sisäkapseli.STEP
3D-mallit/Solidworks/Tulostettavat osat/Rakenna oma mobiilirobotti - Pölykapseli.SLDPRT
3D-mallit/STEP/Rakenna oma mobiilirobotti - Ylärunko.STEP
3D-mallit/STL/Rakenna oma mobiilirobotti - Alarunko.STL
3D-mallit/STL/Rakenna oma mobiilirobotti - Paristopidike.STL
3D-mallit/STL/Rakenna oma mobiilirobotti - Pölykapseli.STL
3D-mallit/STL/Rakenna oma mobiilirobotti - Sisäkapseli.STL
3D-mallit/STL/Rakenna oma mobiilirobotti - Ylärunko.STL

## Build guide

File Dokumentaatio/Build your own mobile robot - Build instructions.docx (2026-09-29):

# Build your own mobile robot

# Build instructions

Blogi | Pullonkaula ry

# Introduction

Welcome to assemble your own mobile robot!

This build-it-yourself mobile robot is sure to impress, as it can be controlled using your own mobile device. It also features a simple collision avoidance system.

Once you have built the robot, you will understand the fundamentals of an embedded system comprising actuators and sensors—the same kind of interaction between actuators and sensors used in other robots.

This guide begins by listing the necessary components and providing some background information on them. Next, the assembly process is described in detail. Finally, you will find a simplified wiring diagram.

You can view a video of the assembly process via the accompanying QR code or link.

QR Code Image

https://youtu.be/AeR3-ane96E

You can also access the robot's project page via the accompanying QR code or link; there, you will find all project-related files, including these instructions!


https://github.com/aapokek/Rakenna-oma-mobiilirobotti

# Needed equipment

The table below lists the components and tools required to build the robot. The table is categorized into 3D-printable parts, components, and tools. You can find the files for the 3D-printable parts in the project folder (Rakenna-oma-mobiilirobotti/3D-mallit/). If you wish to print the parts yourself, use the STL or STEP files. Read more about the components and their uses in the next section!

# Information about the components

WeMos D1 Mini v2 NodeMCU ESP8266 IoT-kehitysalusta | ihmevekotin.fi

## ESP8266 D1 mini

The ESP8266 D1 mini serves as the robot's brain. It is programmed to convert control signals from a smartphone into motor movement. Additionally, it reads distance data from HC-SR04 sensors and halts movement if an obstacle is detected nearby. The L298N mini motor driver and HC-SR04 sensors are connected to the labelled pins on the sides of the ESP8266 D1 mini.

Mini DC-DC Step-down Spannungsregler MP1584EN Buck-virtamoduulin lähtö 0,8--20V 3A
Opencircuit MP1584EN Mini Buck -muunnin 4,5 V - 28 V moduuli

## MP1584EN

The MP1584EN is a voltage converter that steps down and regulates the 6 V voltage from AA batteries to 3.3 V. This 3.3 V supply powers the ESP8266 D1 Mini and the HC-SR04 sensors. Please note the arrow on the back of the component indicating the direction of conversion. You can connect the power wire to either of the adjacent pins.

Mini L298N Motor Driver

## L298N mini + 470 µF

The L298N Mini controls the robot's motors based on signals sent by the ESP8266 D1 Mini. The L298N Mini has 10 connection pins. The component receives power directly from the battery via the +/- pins. The motors themselves connect to the MOTOR-A and MOTOR-B pins. Swapping the motor pin connections reverses the direction of rotation. Motor control is handled via pins IN1, IN2, IN3, and IN4, which are connected to the ESP8266 D1 Mini. Pins IN1 and IN2 control motor A, while IN3 and IN4 control motor B, as shown in the following table:

Motor state | IN1/IN3 | IN2/IN4
Forward | PWM | 0 V
Backwards | 0 V | PWM
Idle | 0 V | 0 V
Break | 3.3 V | 3.3 V

PWM (Pulse Width Modulation), as indicated in the table, is used to control the rotational speeds of the motors. A 470 µF capacitor has been soldered to the power pins of the L298N Mini to smooth out potential current spikes and improve motor performance.

Ultrasonic Sensor - HC-SR04

## HC-SR04

TT DC Motor with Plastic Gearbox – 1:48 Dual Shaft with Wires – Voltaat

The HC-SR04 is a distance sensor that operates using ultrasonic pulses outside the range of human hearing. It functions based on the echo produced by an obstacle; the sensor emits short ultrasonic pulses and listens for their echoes. It can detect obstacles at up to 4 meters. The HC-SR04 has four pins: VCC, GND, Trig, and Echo. Power is supplied via the VCC and GND pins. The Trig pin is used to transmit the pulse. Upon detecting an echo, the sensor sends a signal to the Echo pin, which is registered by the ESP8266. In the robot, these sensors are used to prevent collisions during forward or backward movement. The ESP8266 D1 mini calculates the distance to the obstacle based on the time interval between pulse transmission and reception. In the implemented code, the robot is programmed to stop at 20–50 cm from the obstacle, depending on the set speed.

8-pinninen pikaliitin (Wago tyyppinen) – Pekan Sähkökiituri

## Motors

Wago 5-napainen vipuliitin 6 mm² 6 kpl | Motonet Oy

The robot is driven by small 1:48 geared motors. The yellow gearbox provides the robot with sufficient torque for movement. The motor itself is located at one end of the gearbox and is controlled by applying a voltage of 3–6 V to the power leads. Motor control is handled by an L298N Mini module, with the motor wires connected to its MOTOR-A or MOTOR-B pins. The direction of rotation can be reversed simply by swapping the wires.

## Lever connectors

Premium Jumper Wires Female-Female 250 mm Bundle of 10 – Rocket Scream
10-Way F/M Jumper Wire 20cm – HandsOn Tech

Lever connectors are easy-to-use cable connectors that allow two or more cables to be joined quickly without soldering. The operating principle of the lever connector is simple: first, the lever is opened; then, the cable is inserted into the connector; and finally, the lever is closed. The robot uses 3-, 5-, and 8-pole lever connectors to connect power cables. All ground wires (GND/-) are connected to the largest, 8-pole connector. The 6 V voltage from the batteries is distributed to the 3-pole connector, and the 3.3 V voltage to the 5-pole connector.

## AA batteries

The robot is powered by four standard AA batteries. You can also use rechargeable AA batteries if you wish, but they must be 1.5 V lithium batteries (such as those shown in the image). Please note that standard rechargeable AA batteries often use NiMH chemistry and are therefore unsuitable due to their lower 1.2 V voltage.

## Jumper cables

The components are connected to each other using jumper cables, which come in three types: 0-0, 0-1, and 1-1. Jumper cables allow for quick connections, as soldering is not required. The robot uses eight 0-0 jumper cables and twelve 0-1 jumper cables.

# Build process

The robot assembly process consists of six stages, progressing from installing the code to attaching components and routing wires, followed by testing and finalization. You will find a wiring diagram on the last page of this guide to assist with the connections.

## 1. Uploading the code

The assembly process begins by installing the code onto the ESP8266 D1 Mini. Enter the robot's name and the password to be used on lines 2 and 3 of the code.

String robotName = "MunRobotti";

static const char* AP_PASSWORD = "OmaSalasana";

Later, you will connect to the Wi-Fi network using the name and password you specified. After making the edits, you can connect the ESP8266 D1 Mini to your computer via USB cable and click the blue arrow in the top-left corner of the Arduino IDE. The code has been successfully uploaded when you see the "Done uploading" notification. You can then disconnect the USB cable and proceed to the next step.

## 2. Installing components to the hull

Next, install all the electronic components onto the 3D-printed upper frame.

First, feed the motor wires through the holes on the side and gently press the motors into place. Ensure the wires straighten out and do not get pinched underneath the motor.

Press the following components into their designated slots:

1. ESP8266 D1 mini
2. MP1584EN
3. L298N mini + 470 µF
4. Both HC-SR04 sensors


Next, take the battery holder and ensure its switch is in the OFF position to avoid the risk of a short circuit. Install the AA batteries. Route the battery wire through the small notch and slide the battery holder into place with the batteries facing upwards. Then, press the 3D-printed battery clip into position. The clip secures the batteries in the holder without needing the original battery cover. You can also use the cover that came with the holder, though replacing the batteries will be more difficult.

Great job! After the previous steps, your robot should look roughly like the one in the accompanying image!

Install the lower frame as the base of the robot. Leave the screws for the final assembly. Turn the robot over to connect the wires.

3. Wiring power cables

At this stage, we connect all the robot's power cables. This refers to all the red and black wires shown in the wiring diagram. The robot has a total of 18 power wires, 12 of which are connected using 0-1 jumper cables.

Begin connecting the power wires by attaching the motor power leads to the MOTOR-A and MOTOR-B pins on the L298N Mini. Reversing the motor wire connections will change the motor's direction of rotation; keep this in mind during the testing phase in case a motor spins the wrong way. The connection sequence shown in the wiring diagram has been verified to work correctly.

You can connect the remaining power wires in any order you prefer, but ensure you carry out the following steps.

Ground wire connections:

- Battery black wire (not a jumper cable) → 8-pole lever connector
- ESP8266 D1 mini G → 8-pole lever connector
- MP1584EN IN- → 8-pole lever connector
- MP1584EN OUT- → 8-pole lever connector
- L298N mini - → 8-pole lever connector
- Front HC-SR04 Gnd → 8-pole lever connector
- Rear HC-SR04 Gnd → 8-pole lever connector

6 V wiring:

- Battery red wire (not a jumper cable) → 3-pole lever connector
- MP1584EN IN+ → 3-pole lever connector
- L298N mini + → 3-pole lever connector

3.3 V wiring:

- MP1584EN OUT+ → 5-pole lever connector
- ESP8266 D1 mini 3V3 → 5-pole lever connector
- Front HC-SR04 Vcc → 5-pole lever connector
- Front HC-SR04 Vcc → 5-pole lever connector

## 4. Wiring communication cables

Now that all the components are powered up, it’s time to connect the communication wires!

The robot has a total of 8 communication wires, which are connected using 0-0 jumper wires. Please note that one end of each communication wire is already connected to the ESP8266 D1 Mini.

Make the following connections:

- L298N mini IN1 → ESP8266 D1
- L298N mini IN2 → ESP8266 D2
- L298N mini IN3 → ESP8266 D6
- L298N mini IN4 → ESP8266 D5
- Front HC-SR04 Trig → ESP8266 D7
- Front HC-SR04 Echo → ESP8266 D8
- Rear HC-SR04 Trig → ESP8266 D0
- Rear HC-SR04 Echo → ESP8266 D3


## 5. First test

Have the event supervisor check your wiring before you begin testing!

Your robot is now fully assembled and ready for its first test!

Install the 3D-printed wheel covers onto the wheels, attach the wheels, and turn on the power using the switch on the battery holder. The ESP8266 D1 mini will flash a blue light upon startup. Next, take out your smartphone and navigate to the Wi-Fi settings. Look for the network named after the robot and connect to it using the password you set. Once connected, your phone may automatically open the control interface. However, if nothing happens after connecting, open your phone's web browser and enter the IP address 192.168.4.1 into the address bar. The user interface shown in the accompanying image should then appear on your screen!

Verify the robot's operation by pressing the control buttons. If you notice that either or both motors are spinning in an unexpected direction, swap the power wire connections for the affected motor.

## 6. Wrapping up

Finish assembling the robot by screwing three mounting screws into its base. Finally, bundle the wires together using two cable ties. Note the two attachment points for the cable ties on the chassis. If you wish, you can calibrate your robot to move in a straight line via the calibration menu in the user interface, where you can reduce the motor speed on either side. You can also rename your robot using the naming menu. Please note that after renaming it, you will need to connect to the network using the new name and the original password you set.

Congratulations, your robot is now ready for use!


## Side notes

The batteries last for several hours of active use, provided you remember to turn off the robot after use. You will notice the batteries running low if the connection is suddenly lost. If you plan to operate the robot frequently, we recommend purchasing rechargeable 1.5 V AA lithium batteries (not NiMH); these typically cost between €20 and €30 for a pack of four. They are often available with USB-C charging, eliminating the need for a separate charger.

You can also examine the robot's code, which is in the project folder (Rakenna-oma-mobiilirobotti/Koodit/Mobiilirobotin_koodi/Mobiilirobotin_koodi.ino).

You are free to modify the code as you wish (at your own risk) and update the robot's firmware accordingly. Remember to switch off the battery power before connecting the USB-C cable to the ESP8266. You can find further instructions on installing the code on your computer in the "Code installation" section on the project folder's main page.

# Wiring diagram


REAR

FRONT

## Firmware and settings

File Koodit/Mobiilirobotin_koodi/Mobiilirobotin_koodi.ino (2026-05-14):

// Muokkaa tähän robottisi nimi ja wifi:n salasana:
String robotName = "MunRobotti";
static const char* AP_PASSWORD = "OmaSalasana"; // 8–63 merkkiä

/*
 * ════════════════════════════════════════════════════════
 *  Rakenna oma mobiilirobotti - Pullonkaula ry
 *    Tekijä: Aapo Kekkonen (TG: @aapokek)
 * ════════════════════════════════════════════════════════
 *
 *  Erikseen asennettavat kirjastot:
 *    - ESP8266WiFi
 *    - ESPAsyncTCP
 *    - ESPAsyncWebServer
 *    - DNSServer
 *    - LittleFS
 *
 *  KYTKENNÄT:
 *    - L298N mini
 *      > IN1 → D1 (GPIO5)   Vasen moottori +
 *      > IN2 → D2 (GPIO4)   Vasen moottori -
 *      > IN3 → D6 (GPIO12)  Oikea moottori +
 *      > IN4 → D5 (GPIO14)  Oikea moottori -
 *
 *    - ULTRAÄÄNIANTURIT (HC-SR04):
 *      > Etu Trig → D7 (GPIO13)
 *      > Etu Echo → D8 (GPIO15)
 *      > Taka Trig → D0 (GPIO16)
 *      > Taka Echo → D3 (GPIO0)
 */

#include <ESP8266WiFi.h>
#include <ESPAsyncTCP.h>
#include <ESPAsyncWebServer.h>
#include <DNSServer.h>
#include <LittleFS.h>
#include <algorithm>
#include <math.h>

// ───── Robotin konfiguraatio tallennetaan sisäiseen muistiin ─────
static const char CONFIG_FILE[] = "/robot.cfg";

// ───── WiFi ─────
static constexpr uint16_t DNS_PORT = 53;
static const IPAddress AP_IP(192, 168, 4, 1);

DNSServer dnsServer;

// ───── Moottorien ohjauspinnit ─────
const int IN1 = 5;   // D1 – vasen +
const int IN2 = 4;   // D2 – vasen -
const int IN3 = 12;  // D6 – oikea +
const int IN4 = 14;  // D5 – oikea -

// ───── Ultraäänianturit ─────
const int FRONT_TRIG = 13; // D7
const int FRONT_ECHO = 15; // D8
const int BACK_TRIG  = 16; // D0
const int BACK_ECHO  =  0; // D3

static constexpr float SOUND_CM_PER_US = 0.0343f;
static constexpr uint32_t ECHO_TIMEOUT_US = 25000UL;
static constexpr float NO_ECHO_CM = 999.0f;

// Törmäyksenestoetäisyys skaalautuu nopeuden mukaan lineaarisesti
static constexpr float STOP_MIN_CM = 20.0f;  // Etäisyys minimi nopeudella (10 %)
static constexpr float STOP_MAX_CM = 50.0f;  // Etäisyys maksimi nopeudella (100 %)

// ───── Etäisyydet ─────
float frontCm = NO_ECHO_CM;
float backCm  = NO_ECHO_CM;

// ───── Kalibrointi ─────
float leftCalib  = 1.0f;
float rightCalib = 1.0f;

// ───── Nopeus ─────
int speedPercent = 50;
int speedPWM     = 0;

// ───── Painettujen suuntien järjestys ─────
enum Direction : uint8_t {
  DIR_NONE = 0,
  DIR_FORWARD,
  DIR_BACKWARD,
  DIR_LEFT,
  DIR_RIGHT
};

Direction pressedOrder[4] = {DIR_NONE, DIR_NONE, DIR_NONE, DIR_NONE};
uint8_t pressedCount = 0;

// ───── Anturien ajastus ─────
static constexpr uint32_t SENSOR_INTERVAL_MS = 100UL;
unsigned long lastSensorMs = 0;
bool measureFront = true;

// ───── Tukiaseman uudelleenkäynnistys nimen vaihdon jälkeen ─────
bool apRestartPending = false;
unsigned long apRestartAt = 0;
static constexpr uint32_t AP_RESTART_DELAY_MS = 400UL;

AsyncWebServer server(80);

// ═══════════════════════════════════════════════════════
//  APUFUNKTIOT
// ═══════════════════════════════════════════════════════

static inline int cal(int s, float k) {
  return constrain((int)(s * k), 0, 255);
}

static inline String htmlEscape(const String& in) {
  String out;
  out.reserve(in.length() + 16);
  for (size_t i = 0; i < in.length(); ++i) {
    const char c = in[i];
    switch (c) {
      case '&':  out += F("&amp;");  break;
      case '<':  out += F("&lt;");   break;
      case '>':  out += F("&gt;");   break;
      case '"': out += F("&quot;"); break;
      case '\'': out += F("&#39;"); break;
      default:   out += c; break;
    }
  }
  return out;
}

static String utf8SafeTruncate(const String& in, size_t maxBytes) {
  if (in.length() <= maxBytes) return in;

  const char* data = in.c_str();
  size_t cut = maxBytes;
  while (cut > 0 && ((uint8_t)data[cut] & 0xC0) == 0x80) {
    --cut;
  }
  return in.substring(0, cut);
}

static String buildSsidFromName(const String& name) {
  String ssid = name;
  ssid.trim();
  if (ssid.isEmpty()) ssid = F("Robotti");
  return utf8SafeTruncate(ssid, 32);
}

static const char* dirName(Direction d) {
  switch (d) {
    case DIR_FORWARD:  return "forward";
    case DIR_BACKWARD: return "backward";
    case DIR_LEFT:     return "left";
    case DIR_RIGHT:    return "right";
    default:           return "stopped";
  }
}

static void setPressed(Direction d, bool isPressed) {
  if (isPressed) {
    for (uint8_t i = 0; i < pressedCount; ++i) {
      if (pressedOrder[i] == d) return;
    }
    if (pressedCount < 4) {
      pressedOrder[pressedCount++] = d;
    } else {
      pressedOrder[0] = d;
      pressedCount = 1;
    }
  } else {
    uint8_t out = 0;
    for (uint8_t i = 0; i < pressedCount; ++i) {
      if (pressedOrder[i] != d) {
        pressedOrder[out++] = pressedOrder[i];
      }
    }
    for (uint8_t i = out; i < 4; ++i) {
      pressedOrder[i] = DIR_NONE;
    }
    pressedCount = out;
  }
}

static Direction activeDirection() {
  if (pressedCount == 0) return DIR_NONE;
  return pressedOrder[pressedCount - 1];
}

// ═══════════════════════════════════════════════════════
//  MOOTTORINOHJAUS
// ═══════════════════════════════════════════════════════

void motorStop() {
  digitalWrite(IN1, LOW); digitalWrite(IN2, LOW);
  digitalWrite(IN3, LOW); digitalWrite(IN4, LOW);
}

void motorForward(int s) {
  analogWrite(IN2, cal(s, leftCalib));  digitalWrite(IN1, LOW);
  analogWrite(IN4, cal(s, rightCalib)); digitalWrite(IN3, LOW);
}

void motorBackward(int s) {
  analogWrite(IN1, cal(s, leftCalib));  digitalWrite(IN2, LOW);
  analogWrite(IN3, cal(s, rightCalib)); digitalWrite(IN4, LOW);
}

void motorLeft(int s) {
  analogWrite(IN1, cal(s, leftCalib));  digitalWrite(IN2, LOW);
  analogWrite(IN4, cal(s, rightCalib)); digitalWrite(IN3, LOW);
}

void motorRight(int s) {
  analogWrite(IN2, cal(s, leftCalib));  digitalWrite(IN1, LOW);
  analogWrite(IN3, cal(s, rightCalib)); digitalWrite(IN4, LOW);
}

// ═══════════════════════════════════════════════════════
//  ULTRAÄÄNIMITTAUS
// ═══════════════════════════════════════════════════════

float readDistance(int trigPin, int echoPin) {
  digitalWrite(trigPin, LOW);
  delayMicroseconds(2);
  digitalWrite(trigPin, HIGH);
  delayMicroseconds(10);
  digitalWrite(trigPin, LOW);

  unsigned long duration = pulseIn(echoPin, HIGH, ECHO_TIMEOUT_US);
  if (duration == 0) return NO_ECHO_CM;
  return duration * SOUND_CM_PER_US / 2.0f;
}

// ═══════════════════════════════════════════════════════
//  LIIKKEENHALLINTA
// ═══════════════════════════════════════════════════════

void applyMotion() {
  Direction dir = activeDirection();

  // Törmäyksenestoetäisyys lasketaan lineaarisesti nopeuden mukaan
  float stopCm = STOP_MIN_CM + (STOP_MAX_CM - STOP_MIN_CM) * (speedPercent - 10) / 90.0f;

  if (dir == DIR_FORWARD  && frontCm < stopCm) dir = DIR_NONE;
  if (dir == DIR_BACKWARD && backCm  < stopCm) dir = DIR_NONE;

  switch (dir) {
    case DIR_FORWARD:  motorForward(speedPWM);  break;
    case DIR_BACKWARD: motorBackward(speedPWM); break;
    case DIR_LEFT:     motorLeft(speedPWM);     break;
    case DIR_RIGHT:    motorRight(speedPWM);    break;
    default:           motorStop();             break;
  }
}

void handleButton(Direction direction, bool isPressed) {
  setPressed(direction, isPressed);
  applyMotion();
}

// ═══════════════════════════════════════════════════════
//  NOPEUS
// ═══════════════════════════════════════════════════════

static inline int percentToPWM(int pct) {
  // 10 % → PWM 130
  // 100 % → PWM 255
  return map(constrain(pct, 10, 100), 10, 100, 130, 255);
}

// ═══════════════════════════════════════════════════════
//  TALLENNUS
// ═══════════════════════════════════════════════════════

bool saveConfig() {
  File f = LittleFS.open(CONFIG_FILE, "w");
  if (!f) return false;

  f.println("name=" + robotName);
  f.printf("speed=%d\n", speedPercent);
  f.printf("lcal=%.2f\n", leftCalib);
  f.printf("rcal=%.2f\n", rightCalib);
  f.close();
  return true;
}

bool loadConfig() {
  if (!LittleFS.exists(CONFIG_FILE)) return false;

  File f = LittleFS.open(CONFIG_FILE, "r");
  if (!f) return false;

  while (f.available()) {
    String line = f.readStringUntil('\n');
    line.trim();
    if (line.startsWith("name=")) {
      String v = line.substring(5);
      v.trim();
      if (!v.isEmpty()) robotName = v;
    } else if (line.startsWith("speed=")) {
      int v = line.substring(6).toInt();
      if (v >= 10 && v <= 100) speedPercent = v;
    } else if (line.startsWith("lcal=")) {
      float v = line.substring(5).toFloat();
      if (isfinite(v) && v >= 0.5f && v <= 1.0f) leftCalib = v;
    } else if (line.startsWith("rcal=")) {
      float v = line.substring(5).toFloat();
      if (isfinite(v) && v >= 0.5f && v <= 1.0f) rightCalib = v;
    }
  }
  f.close();

  speedPercent = constrain(speedPercent, 10, 100);
  leftCalib = constrain(leftCalib, 0.5f, 1.0f);
  rightCalib = constrain(rightCalib, 0.5f, 1.0f);
  speedPWM = percentToPWM(speedPercent);
  return true;
}

// ═══════════════════════════════════════════════════════
//  WIFI TUKIASEMA
// ═══════════════════════════════════════════════════════

void startAccessPoint() {
  String ssid = buildSsidFromName(robotName);

  WiFi.persistent(false);
  WiFi.mode(WIFI_OFF);
  delay(50);
  WiFi.mode(WIFI_AP);
  delay(50);

  WiFi.softAPdisconnect(true);
  WiFi.softAPConfig(AP_IP, AP_IP, IPAddress(255, 255, 255, 0));
  bool ok = WiFi.softAP(ssid.c_str(), AP_PASSWORD, 1, false, 4);
  if (!ok) {
    WiFi.softAPdisconnect(true);
    WiFi.softAP("Robotti", AP_PASSWORD, 1, false, 4);
  }

  dnsServer.stop();
  dnsServer.start(DNS_PORT, "*", WiFi.softAPIP());
}

// ═══════════════════════════════════════════════════════
//  WEB-SIVU
// ═══════════════════════════════════════════════════════

static const char PAGE_TMPL[] PROGMEM = R"rawliteral(
<!DOCTYPE HTML>
<html lang="fi">
<head>
<meta charset="UTF-8">
<meta name="viewport" content="width=device-width,initial-scale=1,maximum-scale=1,user-scalable=no">
<title>{{NAME}}</title>
<style>
*{-webkit-user-select:none;user-select:none;-webkit-touch-callout:none;
  -webkit-tap-highlight-color:transparent;touch-action:manipulation;box-sizing:border-box;}
body{font-family:Arial,sans-serif;background:#111;color:#fff;
     margin:0;padding:16px;text-align:center;}
h1{font-size:clamp(26px,7vw,40px);margin:12px 0 16px;word-break:break-word;}
.pad{display:grid;grid-template-columns:repeat(3,90px);
     grid-template-rows:repeat(3,90px);gap:12px;
     margin:0 auto;width:294px;}
.btn{background:#0f9;border:none;border-radius:16px;
     width:90px;height:90px;font-size:36px;
     color:#000;cursor:pointer;
     box-shadow:0 6px 0 #00000044;}
.btn:active{transform:translateY(5px);box-shadow:0 1px 0 #00000044;}
.section{margin:28px auto;width:min(320px,90vw);}
.section-label{font-size:14px;color:#aaa;margin-bottom:8px;}
.speed-row{display:flex;align-items:center;justify-content:center;gap:16px;}
.sb{width:72px;height:56px;font-size:32px;background:#0f9;color:#000;
    border:none;border-radius:12px;cursor:pointer;}
#pct{font-size:52px;font-weight:bold;color:#0f9;min-width:80px;}
.control-row{display:flex;justify-content:center;gap:10px;flex-wrap:wrap;}
.menu-btn{cursor:pointer;font-size:14px;color:#ccc;
          background:#222;border:1px solid #444;
          padding:8px 16px;border-radius:8px;}
.menu{display:none;margin-top:16px;}
.name-section input{
  width:100%;padding:10px 14px;font-size:18px;border-radius:10px;
  border:2px solid #333;background:#222;color:#fff;text-align:center;}
.name-section input:focus{outline:none;border-color:#0f9;}
.name-btn{
  margin-top:10px;width:100%;padding:10px;font-size:16px;
  background:#0f9;color:#000;border:none;border-radius:10px;cursor:pointer;}
.name-btn:active{opacity:.75;}
.name-ok{color:#0f9;font-size:13px;min-height:18px;margin-top:6px;}
#calibMenu{display:none;}
.calrow{display:flex;justify-content:space-around;margin-top:12px;}
.calgroup{display:flex;flex-direction:column;align-items:center;gap:6px;}
.calgroup span{font-size:12px;color:#aaa;}
.csb{width:54px;height:42px;font-size:24px;background:#f90;
     color:#000;border:none;border-radius:8px;cursor:pointer;}
#cal{font-size:14px;color:#f90;margin-top:6px;}
</style>
</head>
<body>

<h1 id="robotTitle">{{NAME}}</h1>

<div class="pad">
  <div></div>
  <button class="btn" id="btnF">▲</button>
  <div></div>

  <button class="btn" id="btnL">◀</button>
  <div></div>
  <button class="btn" id="btnR">▶</button>

  <div></div>
  <button class="btn" id="btnB">▼</button>
  <div></div>
</div>

<div class="section">
  <div class="section-label">Nopeus</div>
  <div class="speed-row">
    <button class="sb" onclick="sendCmd('sd')">–</button>
    <span id="pct">50</span><span style="font-size:28px;color:#0f9;">%</span>
    <button class="sb" onclick="sendCmd('su')">+</button>
  </div>
</div>

<div class="section">
  <div class="control-row">
    <button class="menu-btn" onclick="toggleCalib()">⚙ Kalibrointi</button>
    <button class="menu-btn" onclick="toggleName()">✎ Nimi</button>
  </div>

  <div id="calibMenu" class="menu">
    <div id="cal">V:1.00 O:1.00</div>
    <div class="calrow">
      <div class="calgroup">
        <span>Vasen</span>
        <div>
          <button class="csb" onclick="sendCmd('cld')">–</button>
          <button class="csb" onclick="sendCmd('clu')">+</button>
        </div>
      </div>
      <div class="calgroup">
        <span>Oikea</span>
        <div>
          <button class="csb" onclick="sendCmd('crd')">–</button>
          <button class="csb" onclick="sendCmd('cru')">+</button>
        </div>
      </div>
    </div>
  </div>

  <div id="nameMenu" class="menu name-section">
    <div class="section-label">Robotin nimi</div>
    <input type="text" id="nameInput" maxlength="24" placeholder="Kirjoita nimi tähän…" value="{{NAME}}">
    <button class="name-btn" onclick="saveName()">Tallenna nimi</button>
    <div class="name-ok" id="nameOk"></div>
  </div>
</div>

<script>
function sendCmd(c) {
  return fetch('/' + c, { cache: 'no-store' }).catch(() => {});
}

function bindHold(btnId, pressCmd, releaseCmd) {
  const b = document.getElementById(btnId);
  const down = (e) => {
    e.preventDefault();
    sendCmd(pressCmd);
  };
  const up = (e) => {
    e.preventDefault();
    sendCmd(releaseCmd);
  };
  b.addEventListener('pointerdown', down, { passive: false });
  b.addEventListener('pointerup', up, { passive: false });
  b.addEventListener('pointercancel', up, { passive: false });
  b.addEventListener('pointerleave', up, { passive: false });
  b.addEventListener('contextmenu', e => e.preventDefault());
}

function updateUI() {
  fetch('/g', { cache: 'no-store' }).then(r => r.text()).then(t => {
    document.getElementById('pct').textContent = t;
  }).catch(() => {});
  fetch('/gc', { cache: 'no-store' }).then(r => r.text()).then(t => {
    document.getElementById('cal').textContent = t;
  }).catch(() => {});
  fetch('/gn', { cache: 'no-store' }).then(r => r.text()).then(t => {
    if (t) {
      document.getElementById('robotTitle').textContent = t;
      document.title = t;

      const input = document.getElementById('nameInput');

      if (document.activeElement !== input) {
        input.value = t;
      }
    }
  }).catch(() => {});
}

function saveName() {
  const nameInput = document.getElementById('nameInput');
  const name = nameInput.value.trim();
  if (!name) return;

  fetch('/setname?v=' + encodeURIComponent(name), { cache: 'no-store' })
    .then(r => r.text())
    .then(t => {
      document.getElementById('robotTitle').textContent = t;
      document.title = t;
      document.getElementById('nameInput').value = t;
      const ok = document.getElementById('nameOk');
      ok.textContent = 'Nimi tallennettu! Yhdistä uudelleen uuteen verkkoon.';
      setTimeout(() => ok.textContent = '', 7000);
    }).catch(() => {});
}

function toggleCalib() {
  const c = document.getElementById('calibMenu');
  const n = document.getElementById('nameMenu');

  const open = c.style.display === 'block';
  c.style.display = open ? 'none' : 'block';
  n.style.display = 'none';
}

function toggleName() {
  const c = document.getElementById('calibMenu');
  const n = document.getElementById('nameMenu');

  const open = n.style.display === 'block';
  n.style.display = open ? 'none' : 'block';
  c.style.display = 'none';
}

window.addEventListener('load', () => {
  bindHold('btnF', 'f1', 'f0');
  bindHold('btnB', 'b1', 'b0');
  bindHold('btnL', 'l1', 'l0');
  bindHold('btnR', 'r1', 'r0');
  updateUI();
  setInterval(updateUI, 1000);
});

window.addEventListener('pagehide', () => { sendCmd('stopall'); });
document.addEventListener('visibilitychange', () => {
  if (document.visibilityState === 'hidden') sendCmd('stopall');
});
</script>
</body>
</html>
)rawliteral";

String buildPage() {
  String page = FPSTR(PAGE_TMPL);
  String safe = htmlEscape(robotName);
  page.replace("{{NAME}}", safe);
  return page;
}

// ═══════════════════════════════════════════════════════
//  REITIT
// ═══════════════════════════════════════════════════════

void setupRoutes() {
  server.on("/", HTTP_GET, [](AsyncWebServerRequest* req) {
    AsyncWebServerResponse* res = req->beginResponse(200, "text/html", buildPage());
    res->addHeader("Cache-Control", "no-store");
    req->send(res);
  });

  server.on("/generate_204", HTTP_GET, [](AsyncWebServerRequest* r) { r->redirect("/"); });
  server.on("/hotspot-detect.html", HTTP_GET, [](AsyncWebServerRequest* r) { r->redirect("/"); });
  server.on("/ncsi.txt", HTTP_GET, [](AsyncWebServerRequest* r) { r->send(200, "text/plain", "Microsoft NCSI"); });
  server.on("/connecttest.txt", HTTP_GET, [](AsyncWebServerRequest* r) { r->redirect("/"); });
  server.on("/fwlink", HTTP_GET, [](AsyncWebServerRequest* r) { r->redirect("/"); });
  server.on("/library/test/success.html", HTTP_GET, [](AsyncWebServerRequest* r) { r->redirect("/"); });

  server.on("/f1", HTTP_GET, [](AsyncWebServerRequest* r){ handleButton(DIR_FORWARD,  true);  r->send(200, "text/plain", "OK"); });
  server.on("/f0", HTTP_GET, [](AsyncWebServerRequest* r){ handleButton(DIR_FORWARD,  false); r->send(200, "text/plain", "OK"); });
  server.on("/b1", HTTP_GET, [](AsyncWebServerRequest* r){ handleButton(DIR_BACKWARD, true);  r->send(200, "text/plain", "OK"); });
  server.on("/b0", HTTP_GET, [](AsyncWebServerRequest* r){ handleButton(DIR_BACKWARD, false); r->send(200, "text/plain", "OK"); });
  server.on("/l1", HTTP_GET, [](AsyncWebServerRequest* r){ handleButton(DIR_LEFT,     true);  r->send(200, "text/plain", "OK"); });
  server.on("/l0", HTTP_GET, [](AsyncWebServerRequest* r){ handleButton(DIR_LEFT,     false); r->send(200, "text/plain", "OK"); });
  server.on("/r1", HTTP_GET, [](AsyncWebServerRequest* r){ handleButton(DIR_RIGHT,    true);  r->send(200, "text/plain", "OK"); });
  server.on("/r0", HTTP_GET, [](AsyncWebServerRequest* r){ handleButton(DIR_RIGHT,    false); r->send(200, "text/plain", "OK"); });

  server.on("/su", HTTP_GET, [](AsyncWebServerRequest* r) {
    speedPercent = min(100, speedPercent + 10);
    speedPWM = percentToPWM(speedPercent);
    applyMotion();
    saveConfig();
    r->send(200, "text/plain", String(speedPercent));
  });

  server.on("/sd", HTTP_GET, [](AsyncWebServerRequest* r) {
    speedPercent = max(10, speedPercent - 10);
    speedPWM = percentToPWM(speedPercent);
    applyMotion();
    saveConfig();
    r->send(200, "text/plain", String(speedPercent));
  });

  server.on("/g", HTTP_GET, [](AsyncWebServerRequest* r) {
    r->send(200, "text/plain", String(speedPercent));
  });

  server.on("/clu", HTTP_GET, [](AsyncWebServerRequest* r) {
    leftCalib = constrain(leftCalib + 0.01f, 0.5f, 1.0f);
    applyMotion();
    saveConfig();
    r->send(200, "text/plain", "OK");
  });

  server.on("/cld", HTTP_GET, [](AsyncWebServerRequest* r) {
    leftCalib = constrain(leftCalib - 0.01f, 0.5f, 1.0f);
    applyMotion();
    saveConfig();
    r->send(200, "text/plain", "OK");
  });

  server.on("/cru", HTTP_GET, [](AsyncWebServerRequest* r) {
    rightCalib = constrain(rightCalib + 0.01f, 0.5f, 1.0f);
    applyMotion();
    saveConfig();
    r->send(200, "text/plain", "OK");
  });

  server.on("/crd", HTTP_GET, [](AsyncWebServerRequest* r) {
    rightCalib = constrain(rightCalib - 0.01f, 0.5f, 1.0f);
    applyMotion();
    saveConfig();
    r->send(200, "text/plain", "OK");
  });

  server.on("/gc", HTTP_GET, [](AsyncWebServerRequest* r) {
    String s = "V:" + String(leftCalib, 2) + "  O:" + String(rightCalib, 2);
    r->send(200, "text/plain", s);
  });

  server.on("/setname", HTTP_GET, [](AsyncWebServerRequest* r) {
    String reply = robotName;

    if (r->hasParam("v")) {
      String newName = r->getParam("v")->value();
      newName.trim();
      if (!newName.isEmpty()) {
        robotName = newName;
        saveConfig();
        reply = robotName;
        apRestartPending = true;
        apRestartAt = millis();
      }
    }

    r->send(200, "text/plain", reply);
  });

  server.on("/gn", HTTP_GET, [](AsyncWebServerRequest* r) {
    r->send(200, "text/plain", robotName);
  });

  server.on("/stopall", HTTP_GET, [](AsyncWebServerRequest* r) {
    pressedCount = 0;
    for (uint8_t i = 0; i < 4; ++i) pressedOrder[i] = DIR_NONE;
    motorStop();
    r->send(200, "text/plain", "OK");
  });

  server.onNotFound([](AsyncWebServerRequest* req) {
    req->redirect("/");
  });
}
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
void loop() {
  unsigned long now = millis();

  dnsServer.processNextRequest();

  if (apRestartPending && (now - apRestartAt >= AP_RESTART_DELAY_MS)) {
    apRestartPending = false;
    startAccessPoint();
  }

  if (now - lastSensorMs >= SENSOR_INTERVAL_MS) {
    lastSensorMs = now;

    if (measureFront) {
      frontCm = readDistance(FRONT_TRIG, FRONT_ECHO);
    } else {
      backCm = readDistance(BACK_TRIG, BACK_ECHO);
    }
    measureFront = !measureFront;
    applyMotion();
  }

  yield();
}

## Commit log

2026-05-14 Vaihda käytettyjä pinnejä, tee pysäytymisetäisyydestä skaalautuva nopeuden mukaan ja paranna robotin suorituskykyä
    - Vaihda moottori- ja anturipinnit: IN3/IN4 D7/D8→D6/D5, anturit D6/D5→D7/D8, taka-echo RX→D3 korjatakseen käynnistyksessä esiintyneen moottorin pyörinnän ja koodien latausongelmat komponentit kytket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
    - Korvaa kiinteä STOP_CM nopeuden mukaan skaalautuvalla STOP_MIN/MAX_CM-etäisyydellä
    - Korjaa PWM-minimirajaus 30→130, jotta robotti liikkuu 10 % nopeusasetuksella
    - Alusta moottoripinnit LOWiin heti setup():ssa ennen muita toimintoja
    - Hidasta UI-päivitysväli 800→1000 ms heap-fragmentaation vähentämiseksi
    - Hienosäädä kalibrointiaskel 0.05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
2026-05-17 Lisää robotin 3D-mallit, robotin kasausohje, kuvia ja readme
    [Battery Holder.SLDPRT, ESP8266.SLDASM, L298N mini.SLDASM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]
